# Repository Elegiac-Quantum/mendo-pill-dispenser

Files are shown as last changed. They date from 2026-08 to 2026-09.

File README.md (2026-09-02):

# Mendo 萌豆药盒

### ESP32-S3 smart pill dispenser and medication reminder by EQ Studio

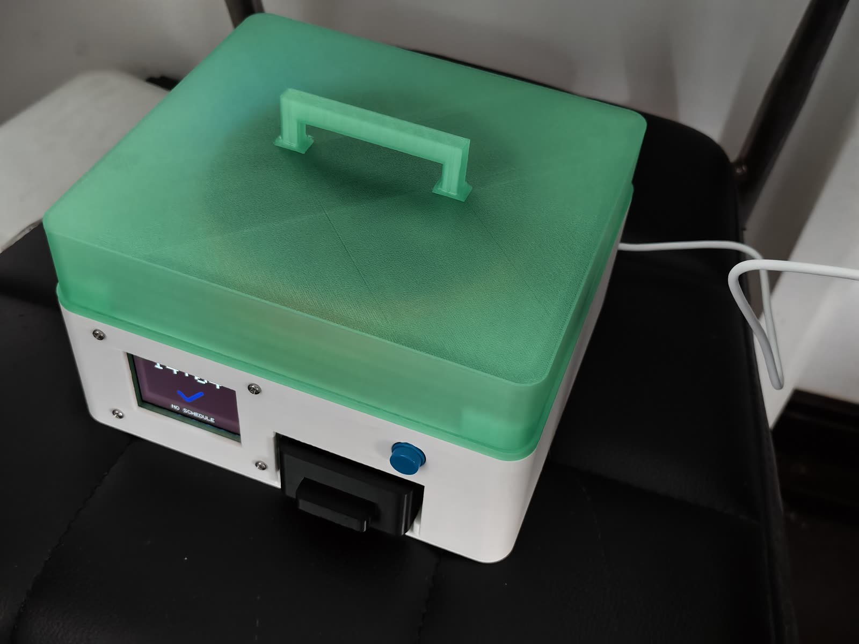
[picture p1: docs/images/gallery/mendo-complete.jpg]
Completed Mendo prototype


Mendo is an experimental ESP32-S3 smart pill dispenser and medication reminder
with a 3D-printed, 15-compartment rotary tray. It combines RTC scheduling,
caregiver web controls, audio alerts and MT6701 position feedback in a compact
assistive-technology prototype by EQ Studio.

This repository contains the ESP-IDF firmware, printable STL/3MF models,
editable OpenSCAD files, assembly documentation and photographs of working
physical prototypes.

**Experimental prototype, not a certified medical device. Do not use it as the
sole safeguard for a person's medication.** See [safety and review](docs/REVIEW.md).

## Hardware

- ALIENTEK DNESP32S3 development board, ESP32-S3 N16R8.
- 2.4-inch display, onboard audio, TF card and DS3231 clock module.
- Continuous-rotation MG996R, PCA9685 channel 0 and MT6701 tray-angle feedback.
- Fifteen preloaded compartments, 24 degrees per step, removable receiving cup.
- Physical confirmation button and local browser settings.

The caregiver loads doses in order. This is not a machine that identifies pills,
counts arbitrary pills, verifies ingestion or decides a medication plan.

## Prototype gallery

<table>
  <tr>
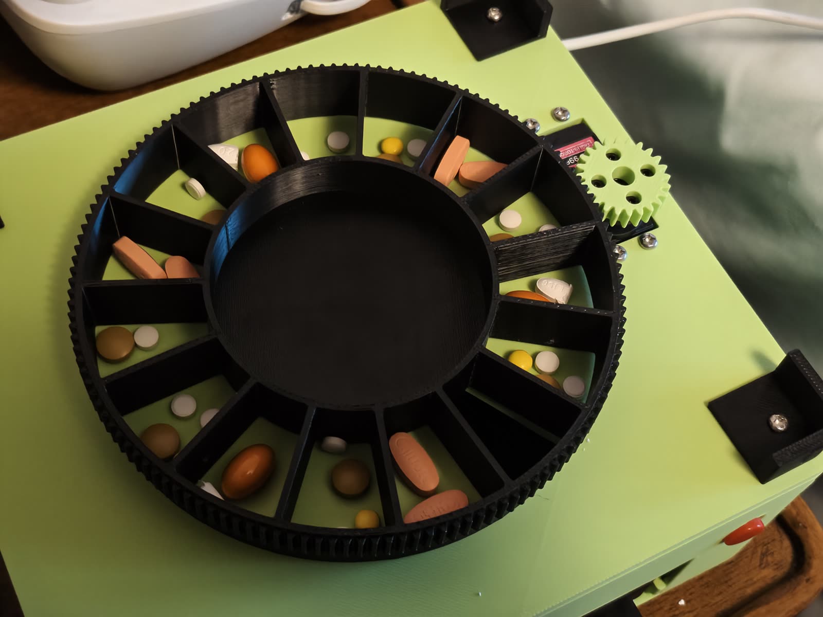
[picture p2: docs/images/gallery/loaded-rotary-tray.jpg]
Fifteen-compartment tray loaded for a mechanism test
    <td width="50%"><br><sub>Fifteen compartments loaded in sequence for a mechanism test.</sub></td>
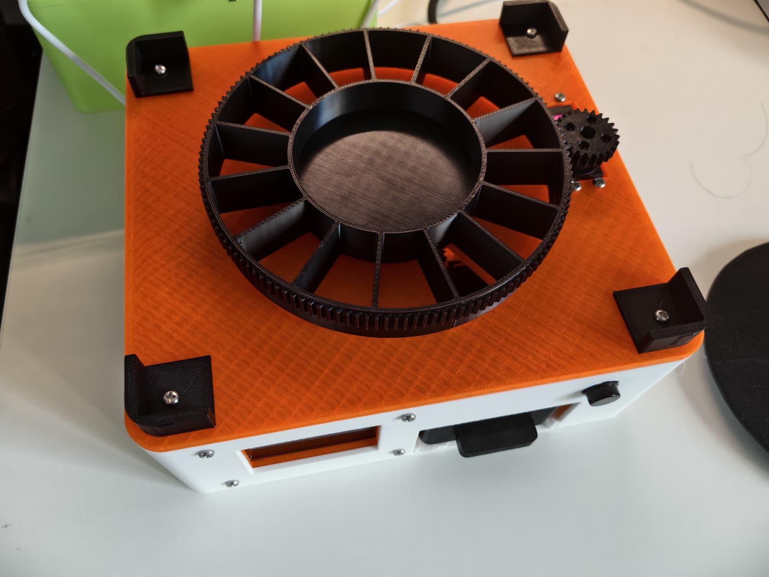
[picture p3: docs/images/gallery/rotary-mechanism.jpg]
Rotary tray and servo pinion
    <td width="50%"><br><sub>The tray's perimeter gear is driven by the servo pinion.</sub></td>
  </tr>
  <tr>
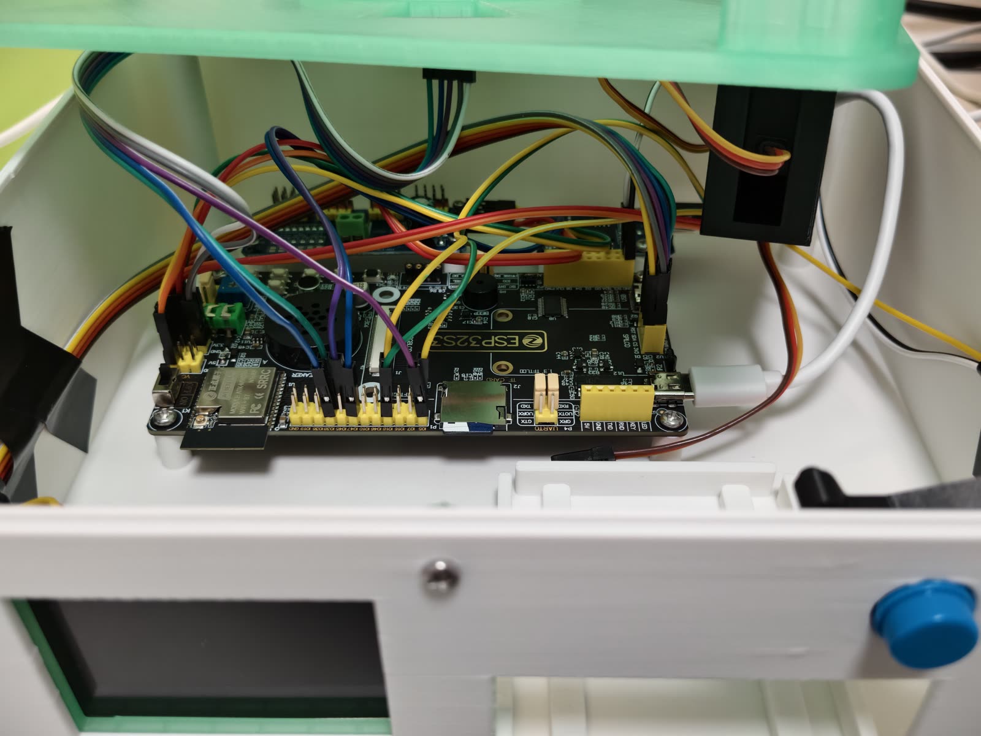
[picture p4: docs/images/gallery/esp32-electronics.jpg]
ESP32-S3 electronics inside the enclosure
    <td><br><sub>ESP32-S3 development board and prototype wiring inside the enclosure.</sub></td>
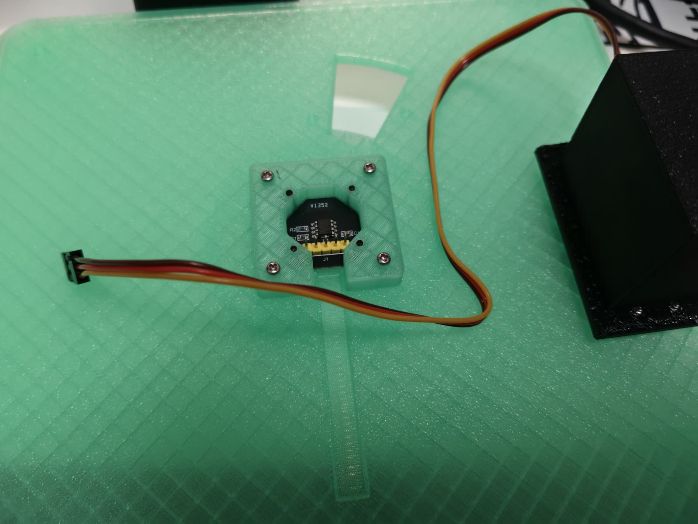
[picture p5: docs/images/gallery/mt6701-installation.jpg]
MT6701 angle sensor installation
    <td><br><sub>MT6701 angle-feedback module held by its printed adapter.</sub></td>
  </tr>
</table>

### From parts to prototype

<table>
  <tr>
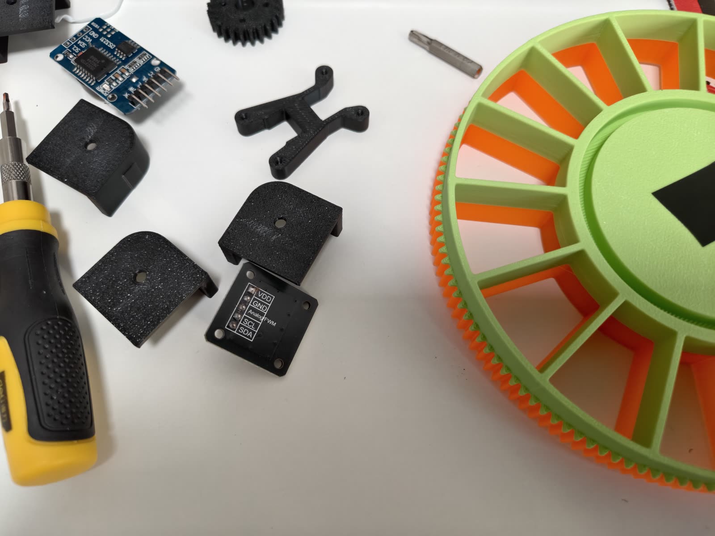
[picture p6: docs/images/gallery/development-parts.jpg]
Printed parts and sensor during development
    <td width="50%"><br><sub>Printed parts, sensor mounts and tray iterations during development.</sub></td>
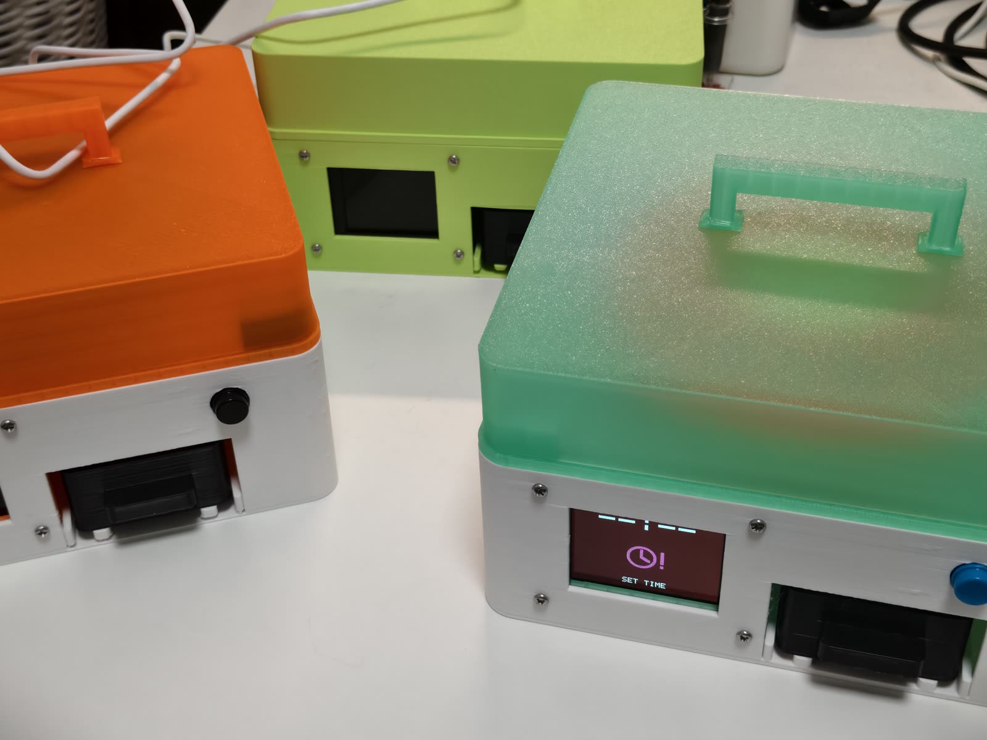
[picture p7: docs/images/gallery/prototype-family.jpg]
Three Mendo prototype builds
    <td width="50%"><br><sub>Several physical builds used to test fit, assembly and repeatability.</sub></td>
  </tr>
</table>

### Geometry previews

These OpenSCAD previews are rendered directly from every triangle in the
published STL geometry. They are not photographs and do not add parts that are
absent from the downloadable files.

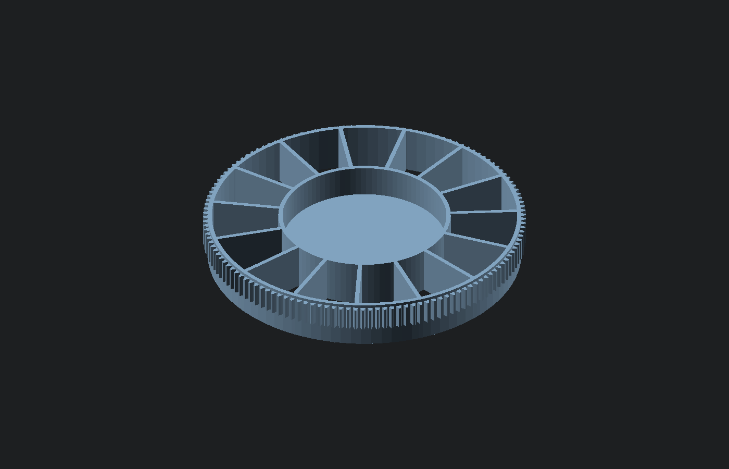
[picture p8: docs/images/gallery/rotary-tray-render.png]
OpenSCAD render of the 15-compartment tray


<table>
  <tr>
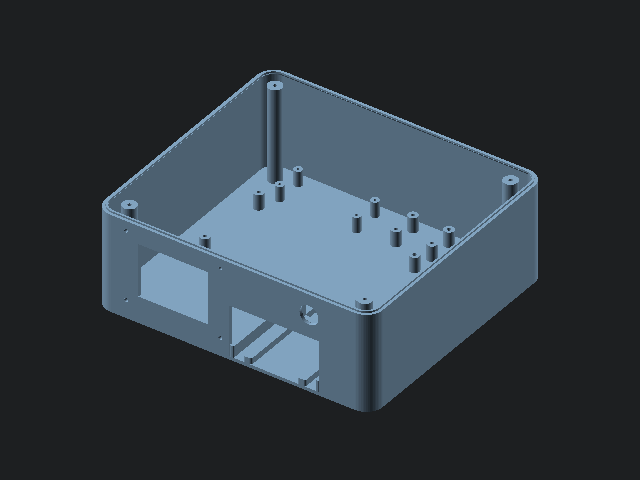
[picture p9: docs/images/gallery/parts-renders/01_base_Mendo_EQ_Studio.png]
Rendered branded base
    <td width="25%"><br><sub>Branded base</sub></td>
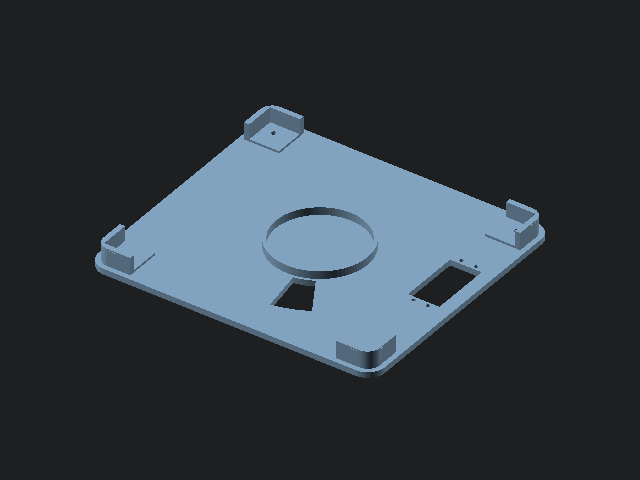
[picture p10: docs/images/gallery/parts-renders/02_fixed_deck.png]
Rendered fixed deck
    <td width="25%"><br><sub>Fixed deck</sub></td>
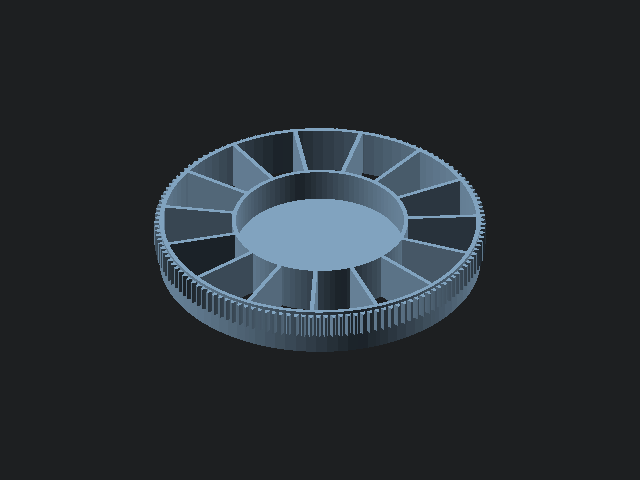
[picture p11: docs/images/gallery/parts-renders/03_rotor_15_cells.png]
Rendered rotary tray
    <td width="25%"><br><sub>Rotary tray</sub></td>
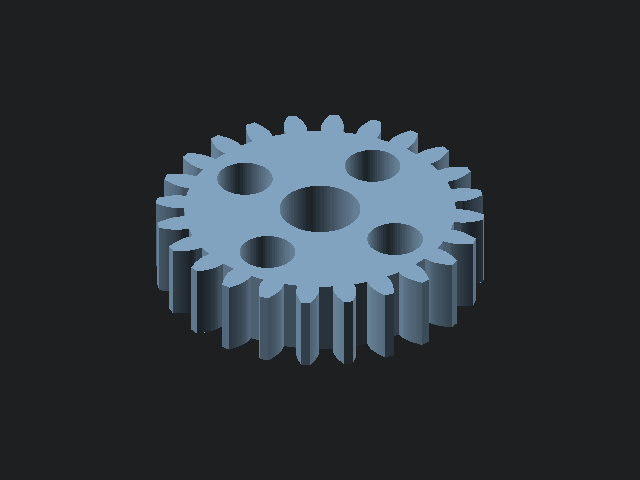
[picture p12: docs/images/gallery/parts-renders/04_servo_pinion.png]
Rendered servo pinion
    <td width="25%"><br><sub>Servo pinion</sub></td>
  </tr>
  <tr>
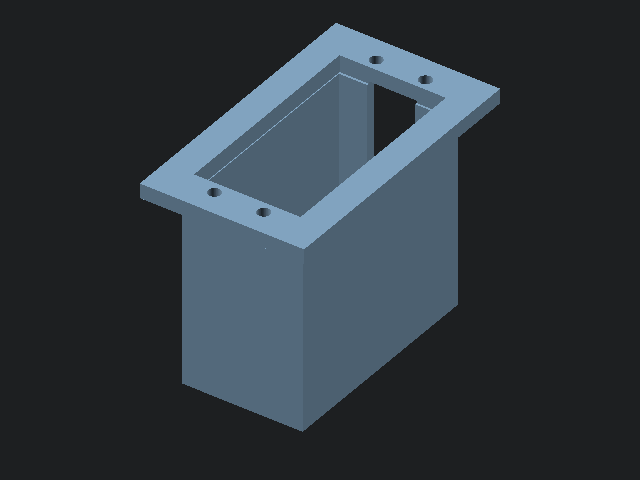
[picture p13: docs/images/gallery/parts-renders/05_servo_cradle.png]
Rendered servo cradle
    <td><br><sub>Servo cradle</sub></td>
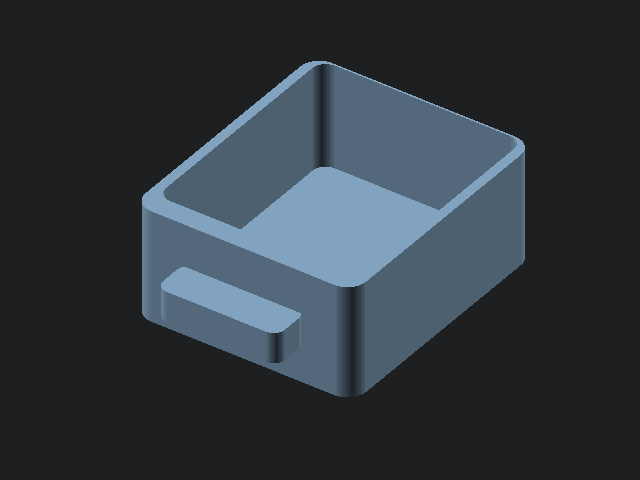
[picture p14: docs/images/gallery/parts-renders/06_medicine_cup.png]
Rendered medicine cup
    <td><br><sub>Medicine cup</sub></td>
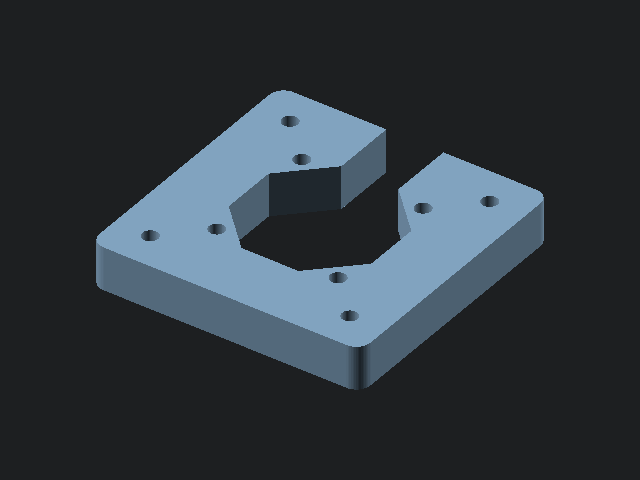
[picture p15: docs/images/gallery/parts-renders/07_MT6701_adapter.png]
Rendered MT6701 adapter
    <td><br><sub>MT6701 adapter</sub></td>
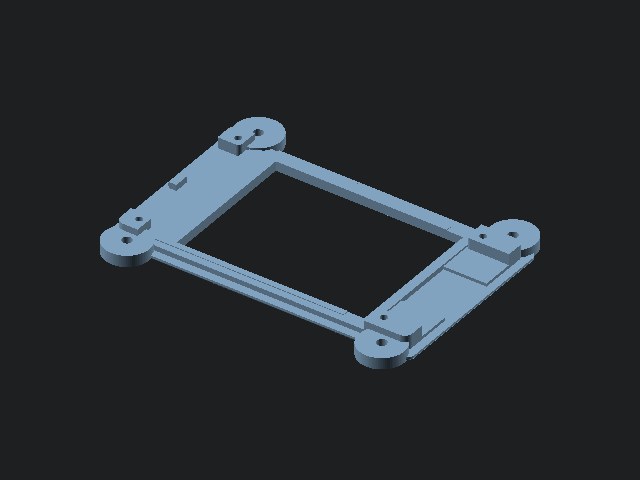
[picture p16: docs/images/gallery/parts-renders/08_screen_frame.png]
Rendered screen frame
    <td><br><sub>Screen frame</sub></td>
  </tr>
  <tr>
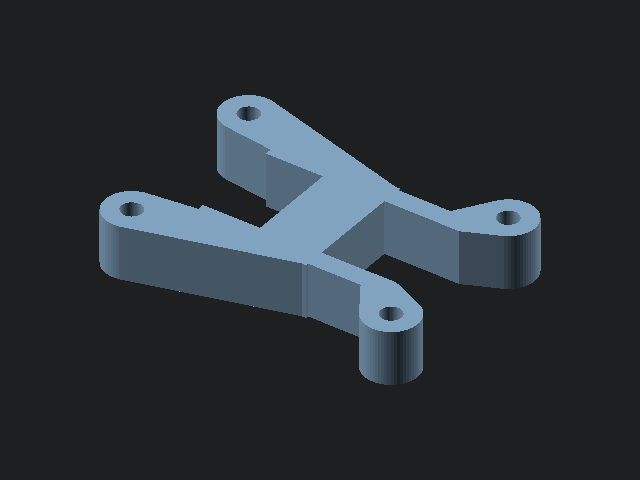
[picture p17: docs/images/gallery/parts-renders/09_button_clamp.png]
Rendered button clamp
    <td><br><sub>Button clamp</sub></td>
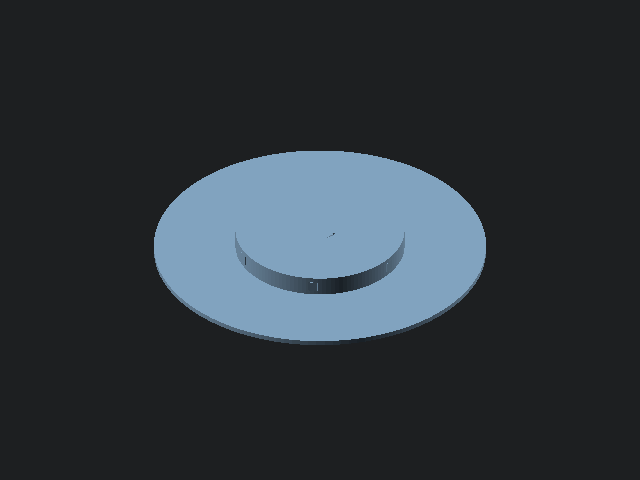
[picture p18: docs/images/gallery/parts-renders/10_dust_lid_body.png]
Rendered dust lid
    <td><br><sub>Dust lid</sub></td>
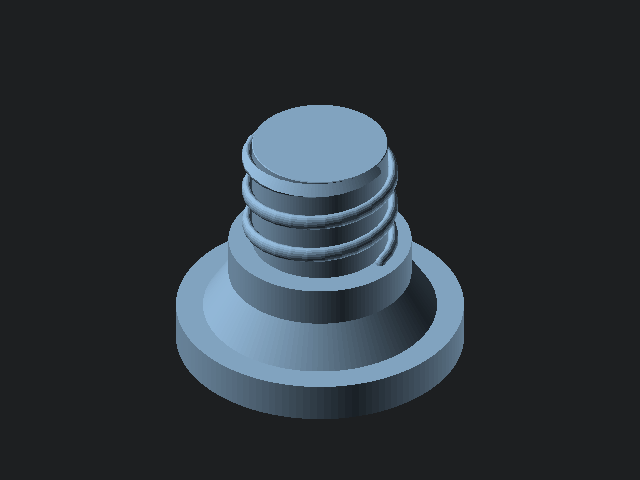
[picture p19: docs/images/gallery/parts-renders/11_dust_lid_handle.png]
Rendered lid handle
    <td><br><sub>Lid handle</sub></td>
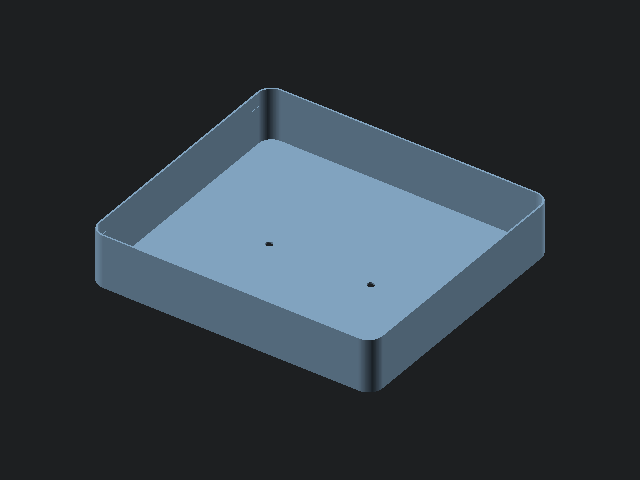
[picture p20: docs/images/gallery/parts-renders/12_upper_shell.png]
Rendered upper shell
    <td><br><sub>Upper shell</sub></td>
  </tr>
  <tr>
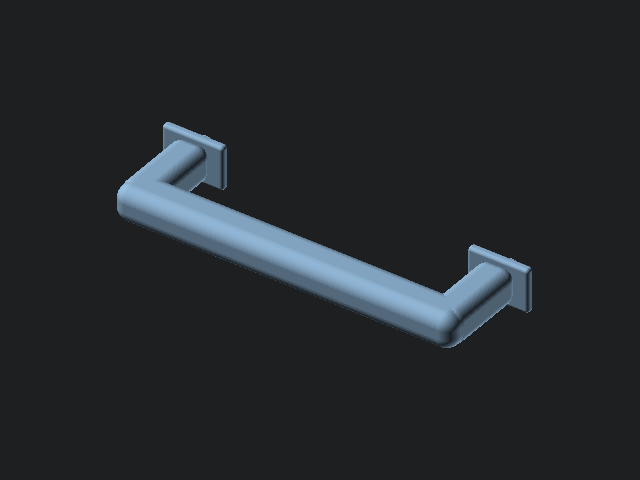
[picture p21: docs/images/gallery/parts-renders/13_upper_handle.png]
Rendered upper handle
    <td><br><sub>Upper handle</sub></td>
  </tr>
</table>

## Repository

| Folder | Contents |
| --- | --- |
| `firmware/` | ESP-IDF source candidate and host tests |
| `models/stl/` | Current selected printable parts; see the model notes |
| `models/cad/` | Editable CAD and underside EQ Studio attribution |
| `docs/` | Review, limitations and provenance |

Read [model notes](docs/MODELS.md) before printing. The original development
workspace, account settings, patient logs and private voice recordings are not included.

## Build

Use ESP-IDF **5.5.4**, target `esp32s3`, with its Python environment activated:

```sh
cd firmware
idf.py set-target esp32s3
idf.py build
```

Review the board pin mapping in `components/board_support/include` before wiring
or flashing. Public source includes neutral generated tones instead of private
voice recordings. It is not a byte-for-byte copy of firmware already installed.
AI wake is disabled in this stability-focused snapshot; do not expect voice wake
to work merely because the Xiaozhi integration source is present.

## Authorship and credit

Project author: **EQ Studio**, maintained on GitHub by **Elegiac-Quantum**.
Preferred credit: **Mendo by EQ Studio**, linked to this repository. Retain the
author notices and identify your modifications; do not present an unchanged copy
as your own original project or imply endorsement.

This is a public source-visible project, not currently an OSI open-source license
grant. Original material is reserved under [LICENSE](LICENSE.md). Third-party
components retain their own licenses. See [credits](THIRD_PARTY_NOTICES.md).

Publication history and file hashes help document this version's provenance;
they are not proof that every underlying idea was invented here, or a guarantee
against copying.

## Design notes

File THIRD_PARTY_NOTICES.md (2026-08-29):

# Sources and third-party credits

Mendo's project authorship is attributed to EQ Studio. This does not mean every
dependency, component, algorithm or earlier mechanism was created by EQ Studio.

- [Espressif ESP-IDF](https://github.com/espressif/esp-idf), version 5.5.4:
  installed separately; retain its Apache-2.0 and component-specific notices.
- ESP-SR, ESP Codec Dev, ESP WebSocket Client, ESP-DSP and Opus dependencies:
  resolved by the dependency manifests and lockfile. Their upstream notices and
  licenses remain applicable; SDK and managed-component caches are not bundled.
- [Xiaozhi ESP32](https://github.com/78/xiaozhi-esp32): implementation reference
  and service ecosystem. Xiaozhi service accounts and voice rights are separate.
- [Shaztech/Pilldispenser](https://github.com/Shaztech/Pilldispenser): an early
  mechanism and software reference. Original downloaded sample files are not
  included. Do not claim Mendo invented pill dispensers or their general concept.
- ALIENTEK DNESP32S3 vendor documentation and examples informed board mapping.
  Vendor PDFs, example archives and branding are not redistributed.
- [OpenSCAD MCAD](https://github.com/openscad/MCAD), used by gear CAD; install
  separately with OpenSCAD and retain its own notices for the library.

Generated neutral tones in this candidate are mathematical sine signals, not
family voice clones or licensed songs. The selected photograph is supplied by
the project owner and re-encoded without camera metadata.

A complete line-by-line third-party provenance review is still pending. This
notice is an inventory of known sources, not a claim that attribution alone
replaces permission. Unclear assets should stay out of a public release until
their provenance and terms are resolved.

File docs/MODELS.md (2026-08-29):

# Model selection

This candidate uses the later V16 base and V7 deck, rather than the stale
13-file package prepared before the final mounting revisions.

1. Base, with a 0.5 mm deep underside `Mendo by EQ Studio` engraving.
2. Fixed deck with integrated upper-shell feet and underside locating groove.
3. 15-compartment rotor gear.
4. 24-tooth pinion for the supplied servo horn.
5. MG996R cradle.
6. Direct-drop receiving cup.
7. 6 mm MT6701 adapter, 17 mm sensor and 28 mm deck hole spacing.
8. Screen frame with its inner window aligned to the base.
9. Four-hole 6 mm button back clamp.
10. Threaded dust-lid body.
11. Threaded dust-lid handle.
12. Upper shell.
13. Rounded upper-shell handle.

The deck has integrated feet: do not add the old loose four-foot set. Old board
edge clamp arrays and the one-piece dust lid are not this version's assembly.

STLs are source meshes, not printer profiles. Check orientation, material,
clearances and supports in your slicer. A combined 3MF is an object collection,
not a promise that all parts fit on one print plate. Engraving has not been
physically printed in this review. Preserve the original unbranded base as a
reference; only print one base.

OpenSCAD CAD uses the MCAD library shipped with OpenSCAD. Some older modules in
the source describe earlier assemblies; the STL list above defines this
candidate. The inherited name `as5600` in a CAD path is historical; this
prototype's sensor is MT6701.

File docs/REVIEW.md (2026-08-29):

# Release-candidate review

Status: local review candidate, not a safety certification or clinical validation.

## Verified during this review

- Existing host C test suite: 14/14 pass after the final motion-safety change.
- Added volume regression executed real production getter/setter with an NVS
  test backend enforcing the 15-character key limit. Before the fix, lowering
  volume to 35 reverted to 100 on simulated reboot. After the fix, 35 and mute
  persist. The setter also records completion of the volume migration.
- Development ESP-IDF firmware rebuilt successfully after this change.
- Added an alignment contract regression. Overshoot outside the same 1.5-degree
  settling tolerance is now reported as `overshot_target`, rather than success.
- Thirteen selected STL files passed closed, positive-volume mesh checks. The
  generated 3MF was reopened and contains 13 separate objects with triangles.
- No physical dispensing or firmware flashing was performed in this review.

## Findings that limit use

1. **Uncollected doses can accumulate.** The next scheduled occurrence proceeds
   even when the prior reminder was not acknowledged. There is no cup-contents
   detector. Never interpret button acknowledgement as verified ingestion.
2. **The overshoot software fault is corrected but needs physical retesting.**
   The controller now fails closed outside 1.5 degrees and never reverses. This
   can turn a formerly reported success into a visible dispense fault, which is
   intentional. The changed build was not flashed or physically exercised here.
3. **Duplicate suppression has limited history.** NVS `dose_state/latest` stores
   only one occurrence; reminder `last_N` keys use list indices. Clock rollback,
   reordering/deleting schedules or interrupted multi-schedule processing need
   persistent per-occurrence coverage. Current tests do not prove those cases.
4. **Scheduling and playback share a task.** Removing the endless alarm loop
   prevents that known lockup, but synchronous playback can still delay a later
   schedule. The exact-minute matcher needs a catch-up policy before long uploads
   or many simultaneous schedules can be considered reliable.
5. **Local security is limited.** Caregiver PIN is optional, local HTTP is not
   encrypted, and the default hotspot password is derived from the MAC address.
   Use a unique hotspot password and PIN on a trusted network; do not forward
   the device's HTTP port to the Internet. Remote control needs a separately
   secured HTTPS service; no live service credentials are published here.
6. **Audio still requires in-room testing.** The 12x software gain saturates
   peaks. A successful build cannot establish audibility, intelligibility,
   absence of distortion or suitability for a particular person's hearing.
7. **AI is not a verified feature of this candidate.** The stability snapshot
   disables the wake task after prior failures. The online service is separate.

These findings must not be replaced with a blanket statement that all functions
are working. Use placebo contents for engineering tests. A caregiver must review
the tray, cup, time, loading order and power-recovery state.

## Excluded from public files

SDK caches, binaries/flashed images, NVS data, device account bindings, Wi-Fi
settings, fleet credentials, logs, patient schedules, family recordings, APK
signing material, vendor PDFs, presentation files and obsolete prototype trees.

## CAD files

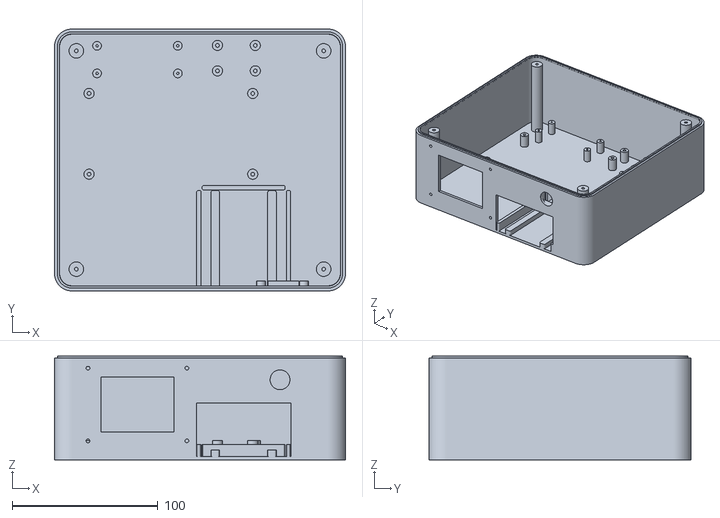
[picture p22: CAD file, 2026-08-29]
models/cad/base_unbranded.stl
200.0 x 180.0 x 71.2

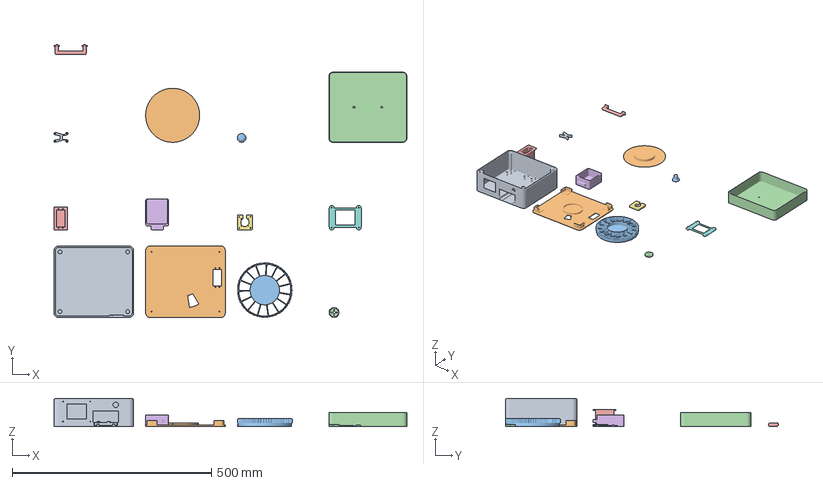
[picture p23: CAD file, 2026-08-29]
models/Mendo_ALL_PARTS_CANDIDATE.3mf
886.0 x 685.8 x 71.2 mm
01_base_Mendo_EQ_Studio
02_fixed_deck
03_rotor_15_cells
04_servo_pinion
05_servo_cradle
06_medicine_cup
07_MT6701_adapter
08_screen_frame
09_button_clamp
10_dust_lid_body
11_dust_lid_handle
12_upper_shell
13_upper_handle

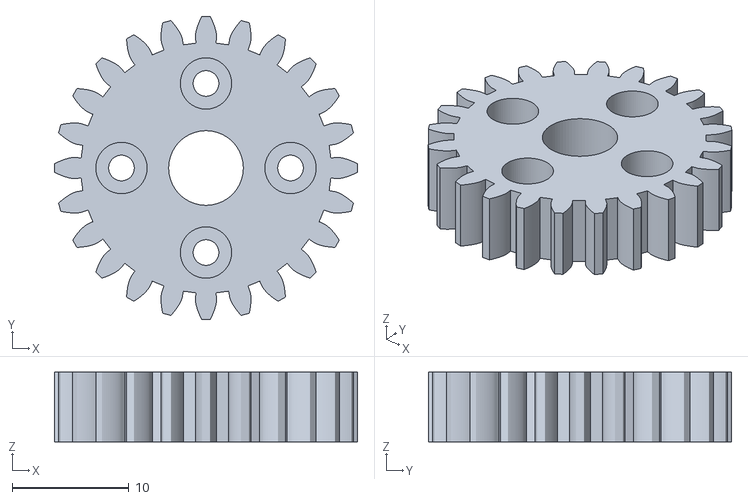
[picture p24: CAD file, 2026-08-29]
models/stl/04_servo_pinion.stl
26.0 x 26.0 x 6.00

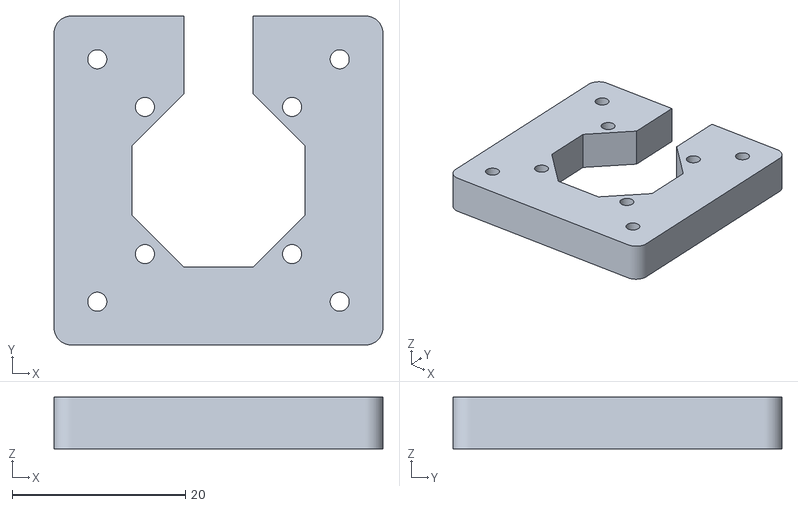
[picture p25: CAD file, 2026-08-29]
models/stl/07_MT6701_adapter.stl
38.0 x 38.0 x 6.00

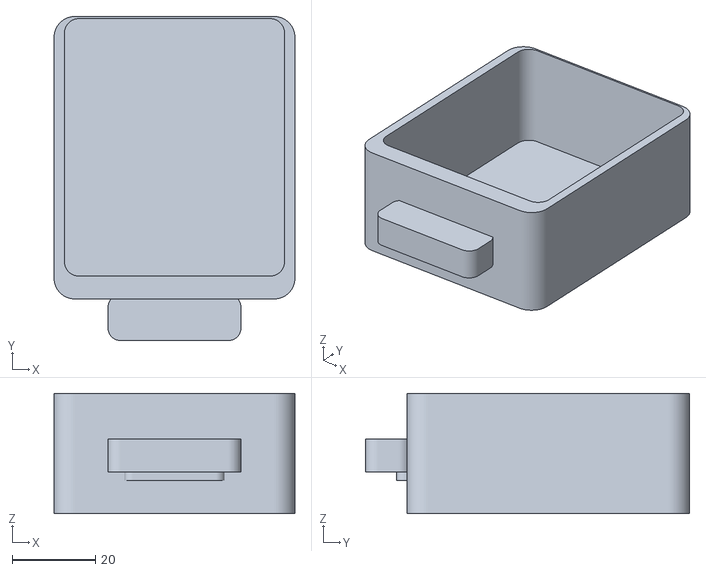
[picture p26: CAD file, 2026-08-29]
models/stl/06_medicine_cup.stl
58.0 x 78.0 x 29.0

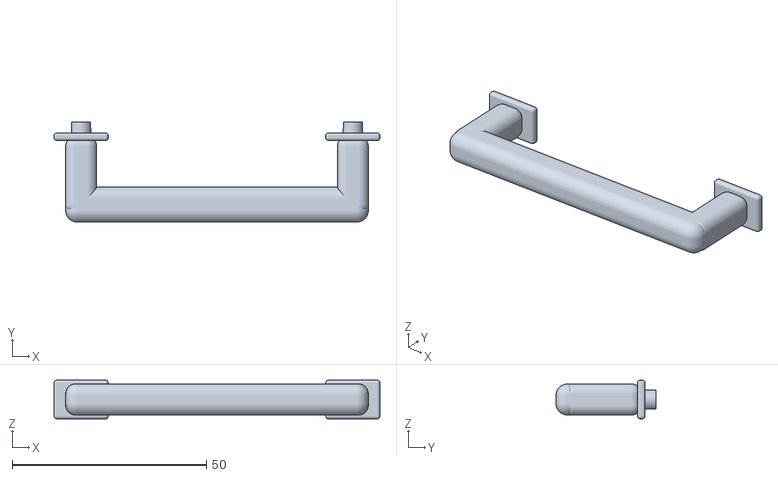
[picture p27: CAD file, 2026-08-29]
models/stl/13_upper_handle.stl
84.0 x 25.8 x 10.00

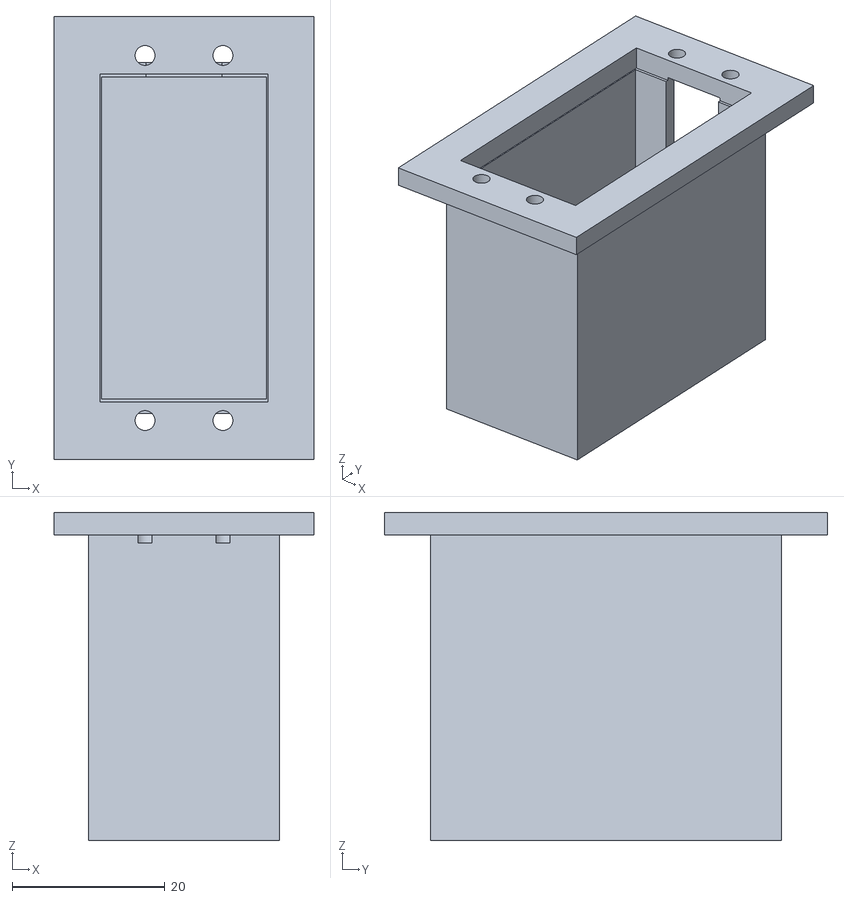
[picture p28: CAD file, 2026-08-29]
models/stl/05_servo_cradle.stl
34.0 x 58.0 x 43.0

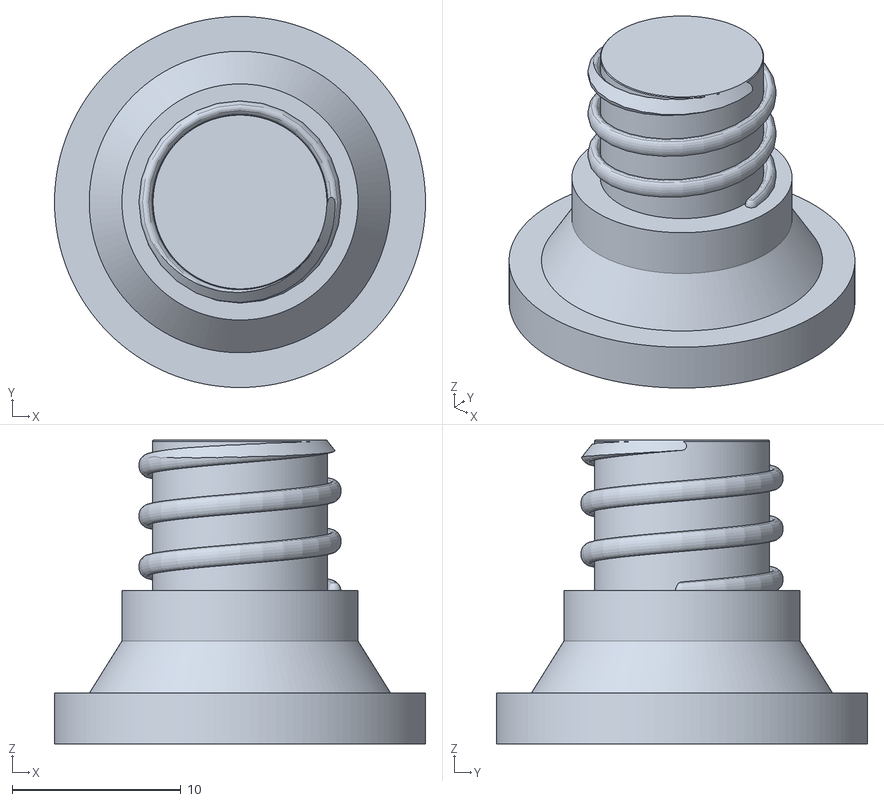
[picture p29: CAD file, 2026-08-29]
models/stl/11_dust_lid_handle.stl
22.0 x 22.0 x 18.0

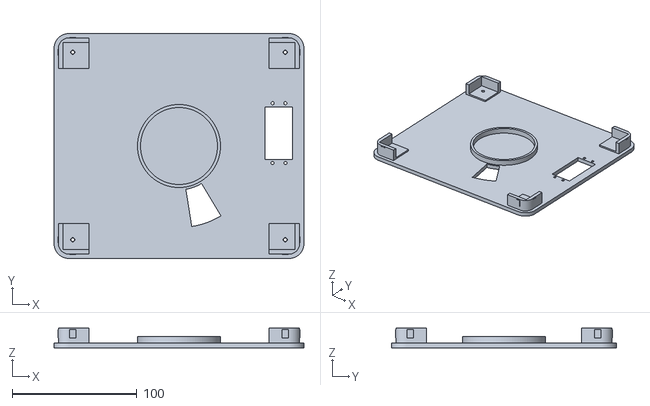
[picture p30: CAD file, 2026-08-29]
models/stl/02_fixed_deck.stl
200.0 x 180.0 x 16.0

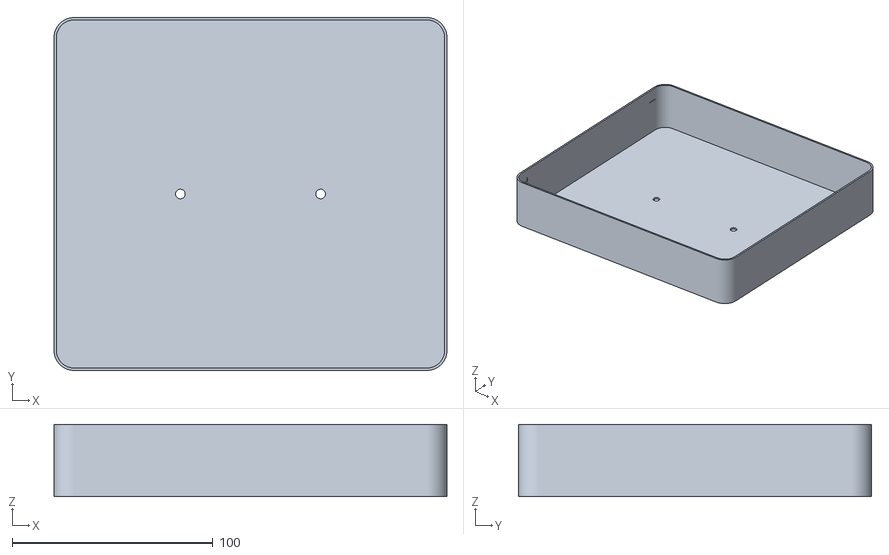
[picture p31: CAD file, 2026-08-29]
models/stl/12_upper_shell.stl
196.0 x 176.0 x 36.0

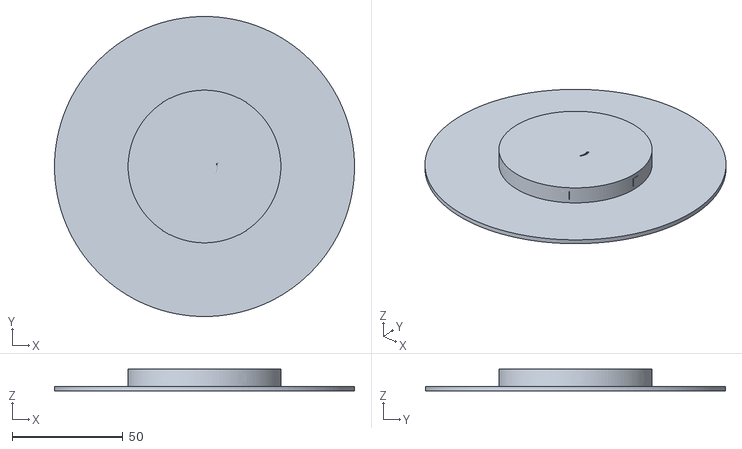
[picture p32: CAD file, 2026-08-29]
models/stl/10_dust_lid_body.stl
135.6 x 135.6 x 9.80

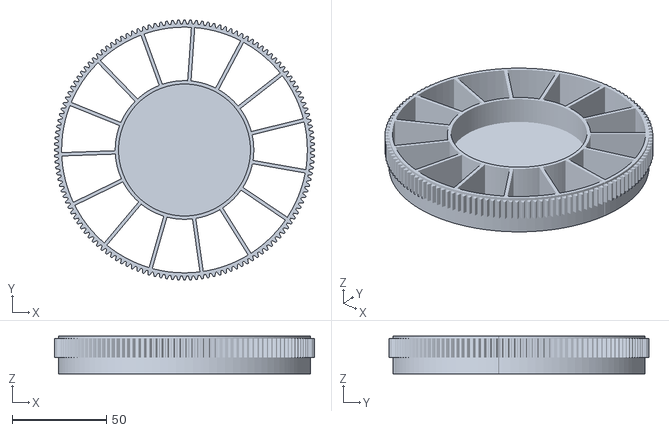
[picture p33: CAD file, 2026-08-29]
models/stl/03_rotor_15_cells.stl
138.0 x 138.0 x 20.0

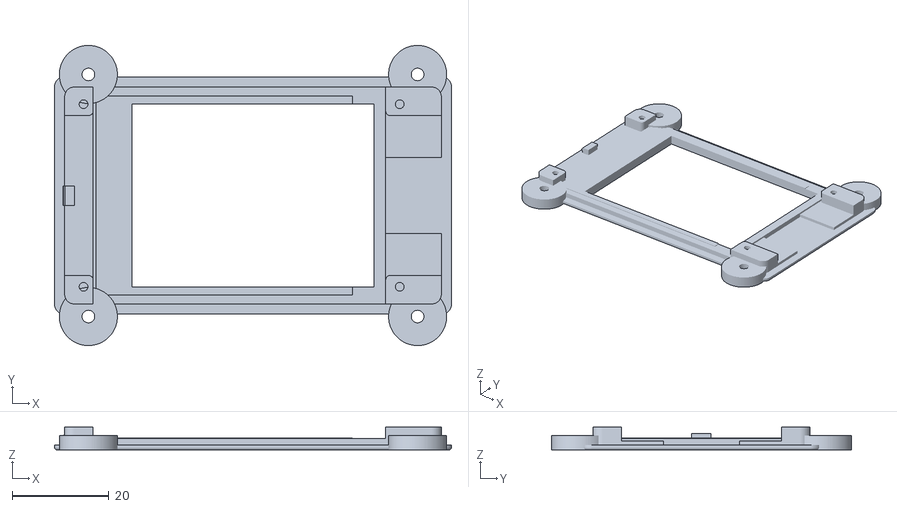
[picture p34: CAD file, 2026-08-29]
models/stl/08_screen_frame.stl
82.0 x 62.0 x 4.70

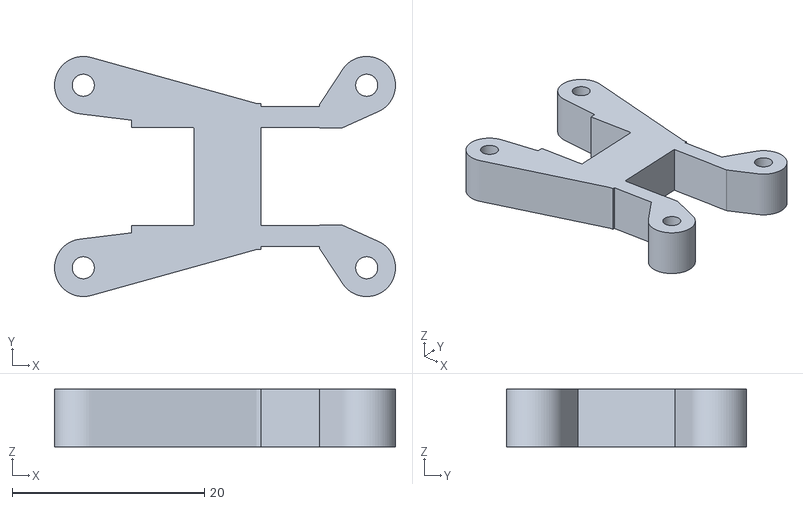
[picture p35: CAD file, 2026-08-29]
models/stl/09_button_clamp.stl
35.5 x 25.0 x 6.00

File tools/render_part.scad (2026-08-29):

// Headless OpenSCAD wrapper used to generate accurate README previews.
// Pass part_path and part_color with -D on the command line.

$fn = 64;
color(part_color)
    import(part_path, convexity = 12);

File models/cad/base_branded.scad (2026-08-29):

// Mendo by EQ Studio. Underside engraving only; all fit geometry is preserved.
// Source: V16 base(), 200 x 180 x 71.2 mm including locating lip.
// The 0.5 mm recess leaves 1.9 mm of the original 2.4 mm floor.
use <mg996r_as5600_gear_v1/mg996r_as5600_gear_v1.scad>
difference() {
    base();
    translate([0,20,0.5]) rotate([180,0,0])
        linear_extrude(height=0.6)
            text("Mendo by EQ Studio", size=5,
                 font="Liberation Sans:style=Bold", halign="center", valign="center");
}

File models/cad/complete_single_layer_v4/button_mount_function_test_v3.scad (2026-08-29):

// Functional button mounting coupon: wall section + screw-on U clamp.
// Measured PCB: 20 x 13 mm; button centre 7 mm from left edge.
$fn = 64;
part = is_undef(part) ? "print_plate" : part;

wall_t = 2.4;
coupon = [40,30];
button_d = 13.6;
board = [20.0,13.0,1.6];
fit = 0.35;
board_cx = board[0]/2-7.0; // +3 mm relative to button centre
guide_t = 1.2;
switch_body = [11.5,11.5,3.0];
moving_neck_h = 4.5;
cap_d = 13.0;
cap_h = 5.0;
seat_h = switch_body[2]+board[2]-0.1; // 4.5 mm; 0.1 mm clamp preload
m2_pilot = 1.7;
m2_clear = 2.3;
screw_x_left = -13.0;
screw_x_right = 16.5;
screw_xs = [screw_x_left,screw_x_right];
screw_y = 9.5;
boss_d = 6.0;
clamp_t = 6.0;

left = board_cx-(board[0]+fit)/2;
right = board_cx+(board[0]+fit)/2;
bottom = -(board[1]+fit)/2;
top = (board[1]+fit)/2;

module wall_coupon() {
    difference() {
        union() {
            difference() {
                translate([0,0,wall_t/2]) cube([coupon[0],coupon[1],wall_t],center=true);
                translate([0,0,-0.1]) cylinder(d=button_d,h=wall_t+0.2);
            }
            // Three locating edges; the right side is open for the 3-pin plug.
            translate([left-guide_t/2,0,wall_t+seat_h/2])
                cube([guide_t,board[1]+fit+2*guide_t,seat_h],center=true);
            for(y=[bottom-guide_t/2,top+guide_t/2])
                translate([(left+right)/2,y,wall_t+seat_h/2])
                    cube([right-left,guide_t,seat_h],center=true);
            for(x=screw_xs,y=[-screw_y,screw_y])
                translate([x,y,wall_t]) cylinder(d=boss_d,h=seat_h);
        }
        for(x=screw_xs,y=[-screw_y,screw_y])
            // Blind thread paths; use M2 x 10 mm with the 6 mm clamp.
            translate([x,y,0.8]) cylinder(d=m2_pilot,h=wall_t+seat_h-0.6);
    }
}

module back_clamp() {
    bridge_x = board_cx; // user-validated clear centre band, away from solder joints
    bridge_w = 7.0;      // includes 2 mm extra support toward the M2 holes
    bridge_cx = bridge_x-1.0; // keep the far edge fixed; extend only hole-ward
    difference() {
        union() {
            // Centre bridge avoids the solder joints near the former left edge.
            translate([bridge_cx,0,clamp_t/2])
                cube([bridge_w,board[1]+2.2,clamp_t],center=true);
            for(y=[-6.2,6.2])
                translate([(left+right)/2-0.4,y,clamp_t/2])
                    cube([right-left+0.8,2.2,clamp_t],center=true);
            // Existing left pair connects to the strengthened centre bridge.
            for(y=[-screw_y,screw_y])
                hull() {
                    translate([screw_x_left,y,0]) cylinder(d=boss_d,h=clamp_t);
                    translate([bridge_cx,y*0.66,clamp_t/2])
                        cube([bridge_w,2.4,clamp_t],center=true);
                }
            // New right pair joins the top/bottom rails while leaving the
            // central 3-pin connector path completely open.
            for(y=[-screw_y,screw_y])
                hull() {
                    translate([screw_x_right,y,0]) cylinder(d=boss_d,h=clamp_t);
                    translate([right-0.4,y*0.66,clamp_t/2])
                        cube([2.4,2.4,clamp_t],center=true);
                }
        }
        for(x=screw_xs,y=[-screw_y,screw_y])
            translate([x,y,-0.1]) cylinder(d=m2_clear,h=clamp_t+0.2);
    }
}

module print_plate() {
    translate([-23,0,0]) wall_coupon();
    translate([22,0,0]) back_clamp();
}

module assembly_preview() {
    wall_coupon();
    // Conservative reference for the measured button stack.
    color("Orange",0.8)
        translate([0,0,wall_t+switch_body[2]/2])
            cube(switch_body,center=true);
    color("Orange",0.8)
        translate([0,0,wall_t-moving_neck_h/2])
            cylinder(d=9.0,h=moving_neck_h,center=true);
    color("Red",0.8)
        translate([0,0,wall_t-moving_neck_h-cap_h/2])
            cylinder(d=cap_d,h=cap_h,center=true);
    color("FireBrick",0.7)
        translate([board_cx,0,wall_t+switch_body[2]+board[2]/2])
            cube(board,center=true);
    color("DimGray") translate([0,0,wall_t+seat_h]) back_clamp();
}

if(part == "wall") wall_coupon();
else if(part == "clamp") back_clamp();
else if(part == "assembly") assembly_preview();
else print_plate();

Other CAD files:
models/stl/01_base_Mendo_EQ_Studio.stl
models/cad/complete_single_layer_v4/complete_single_layer_v4.scad
models/cad/complete_single_layer_v4/mt6701_deck_adapter_17mm.scad
models/cad/complete_single_layer_v4/rotor_dust_lid_15cell.scad
models/cad/complete_single_layer_v4/upper_shell_handle_v2.scad
models/cad/complete_single_layer_v4/upper_shell_snap_v2.scad
models/cad/mg996r_as5600_gear_v1/mg996r_as5600_gear_v1.scad
models/cad/two_part_carousel_v3/two_part_carousel_v3.scad

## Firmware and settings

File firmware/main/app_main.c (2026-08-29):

#include <inttypes.h>

#include "esp_chip_info.h"
#include "esp_event.h"
#include "esp_flash.h"
#include "esp_heap_caps.h"
#include "esp_log.h"
#include "esp_netif.h"
#include "esp_system.h"
#include "driver/uart.h"
#include "esp_adc/adc_oneshot.h"
#include "freertos/FreeRTOS.h"
#include "freertos/task.h"
#include "nvs_flash.h"

#include "board_support/board.h"
#include "pill_ai_transport/transport.h"
#include "pill_app/app.h"
#include "pill_web/web.h"

static const char *TAG = "smartpill";

static void diagnose_mt6701_output(void)
{
    adc_oneshot_unit_handle_t adc = NULL;
    const adc_oneshot_unit_init_cfg_t unit_config = {
        .unit_id = ADC_UNIT_1,
    };
    esp_err_t error = adc_oneshot_new_unit(&unit_config, &adc);
    if (error != ESP_OK) {
        ESP_LOGW(TAG, "MT_OUTPUT error=%s", esp_err_to_name(error));
        return;
    }
    const adc_oneshot_chan_cfg_t channel_config = {
        .atten = ADC_ATTEN_DB_12,
        .bitwidth = ADC_BITWIDTH_12,
    };
    error = adc_oneshot_config_channel(adc, ADC_CHANNEL_4, &channel_config);
    int minimum = 4095, maximum = 0;
    int64_t total = 0;
    int valid = 0;
    if (error == ESP_OK) {
        for (int sample = 0; sample < 1000; ++sample) {
            int raw = 0;
            if (adc_oneshot_read(adc, ADC_CHANNEL_4, &raw) == ESP_OK) {
                if (raw < minimum) minimum = raw;
                if (raw > maximum) maximum = raw;
                total += raw;
                valid++;
            }
            esp_rom_delay_us(100);
        }
    }
    adc_oneshot_del_unit(adc);
    ESP_LOGW(TAG, "MT_OUTPUT gpio=5 samples=%d min=%d max=%d avg=%d span=%d error=%s",
             valid, valid ? minimum : -1, valid ? maximum : -1,
             valid ? (int)(total / valid) : -1,
             valid ? maximum - minimum : -1, esp_err_to_name(error));
}

static void calibration_console(void *unused)
{
    (void)unused;
    ESP_LOGW(TAG, "CAL console ready: send D for MT6701 diagnostics, A for analog output, S to scan safe P1 pins, or T for one empty-tray move");
    for (;;) {
        uint8_t command = 0;
        if (uart_read_bytes(UART_NUM_0, &command, 1, pdMS_TO_TICKS(200)) != 1) continue;
        if (command == 'D') {
            int sda = -1, scl = -1, address = -1;
            uint16_t raw = 0;
            float degrees = 0.0f;
            board_mt6701_diagnose(&sda, &scl, &address);
            esp_err_t mt_error = board_mt6701_read(&raw, &degrees);
            ESP_LOGW(TAG,
                     "MT_DIAG ok=%d sda=%d scl=%d address=%d raw=%u angle=%.2f error=%s",
                     mt_error == ESP_OK, sda, scl, address, raw, degrees,
                     esp_err_to_name(mt_error));
            int half_period_us = -1;
            bool timing_ok = board_mt6701_diagnose_timing(&half_period_us);
            ESP_LOGW(TAG, "MT_TIMING ok=%d half_us=%d approx_khz=%d",
                     timing_ok, half_period_us,
                     timing_ok ? 500 / half_period_us : 0);
            continue;
        }
        if (command == 'S') {
            int sda_gpio = -1, scl_gpio = -1;
            bool found = board_mt6701_scan_safe_p1(&sda_gpio, &scl_gpio);
            ESP_LOGW(TAG, "MT_SCAN found=%d sda_gpio=%d scl_gpio=%d",
                     found, sda_gpio, scl_gpio);
            vTaskDelay(pdMS_TO_TICKS(200));
            esp_restart();
        }
        if (command == 'A') {
            diagnose_mt6701_output();
            continue;
        }
        if (command == 'E') {
            int sda_gpio = -1, scl_gpio = -1;
            bool found = board_mt6701_scan_known_buses(&sda_gpio, &scl_gpio);
            ESP_LOGW(TAG, "MT_EXT_SCAN found=%d sda_gpio=%d scl_gpio=%d",
                     found, sda_gpio, scl_gpio);
            vTaskDelay(pdMS_TO_TICKS(200));
            esp_restart();
        }
        if (command != 'T') continue;
        bool success = board_servo_cycle_channel(0);
        float start = 0.0f, target = 0.0f, final = 0.0f, error = 0.0f;
        const char *reason = "unknown";
        board_servo_last_motion(&start, &target, &final, &error, &reason);
        ESP_LOGW(TAG,
                 "CAL_RESULT success=%d start=%.2f target=%.2f final=%.2f error=%.2f reason=%s",
                 success, start, target, final, error, reason);
    }
}

void app_main(void)
{
    esp_chip_info_t chip_info;
    uint32_t flash_size = 0;

    esp_chip_info(&chip_info);
    ESP_ERROR_CHECK(esp_flash_get_size(NULL, &flash_size));

    ESP_LOGI(TAG, "Smart Pill Dispenser Prototype 2 rotary");
    ESP_LOGI(TAG, "ESP32-S3 cores=%u revision=%u", chip_info.cores, chip_info.revision);
    ESP_LOGI(TAG, "Flash=%" PRIu32 " bytes PSRAM=%u bytes",
             flash_size,
             heap_caps_get_total_size(MALLOC_CAP_SPIRAM));

    esp_err_t error = nvs_flash_init();
    if (error == ESP_ERR_NVS_NO_FREE_PAGES || error == ESP_ERR_NVS_NEW_VERSION_FOUND) {
        ESP_ERROR_CHECK(nvs_flash_erase());
        error = nvs_flash_init();
    }
    ESP_ERROR_CHECK(error);
    ESP_ERROR_CHECK(esp_netif_init());
    ESP_ERROR_CHECK(esp_event_loop_create_default());

    board_health_t health;
    ESP_ERROR_CHECK(board_init(&health));

    esp_err_t console_error = uart_driver_install(UART_NUM_0, 256, 0, 0, NULL, 0);
    if (console_error != ESP_OK && console_error != ESP_ERR_INVALID_STATE) {
        ESP_LOGW(TAG, "COM8 calibration input unavailable: %s",
                 esp_err_to_name(console_error));
    }

    if (xTaskCreate(calibration_console, "cal_console", 3072, NULL, 3, NULL) !=
        pdPASS) {
        ESP_LOGW(TAG, "Calibration console unavailable");
    }

    error = pill_app_start();
    if (error != ESP_OK) {
        ESP_LOGE(TAG, "Safety controller failed: %s; movement remains locked",
                 esp_err_to_name(error));
    }

    error = pill_web_start();
    if (error != ESP_OK) {
        ESP_LOGW(TAG, "Caregiver web UI unavailable: %s", esp_err_to_name(error));
    }
    pill_ai_check_activation_async();
}

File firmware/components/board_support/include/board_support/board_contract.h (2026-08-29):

#ifndef BOARD_SUPPORT_BOARD_CONTRACT_H
#define BOARD_SUPPORT_BOARD_CONTRACT_H

#include <stdbool.h>
#include <stdint.h>

enum {
    BOARD_XL9555_PORT0_SAFE_OUTPUT = 1U << 3,
    BOARD_XL9555_PORT0_BOOT_OUTPUT = 0x08,
    BOARD_XL9555_PORT1_BOOT_OUTPUT = 0x0d,
    BOARD_XL9555_PORT0_BOOT_CONFIG = 0x03,
    BOARD_XL9555_PORT1_BOOT_CONFIG = 0xf0,
    BOARD_LCD_BGR_ORDER = 1,
    BOARD_TF_FORMAT_IF_MOUNT_FAILED = 0,
    BOARD_I2C_SDA_GPIO = 41,
    BOARD_I2C_SCL_GPIO = 42,
    BOARD_RTC_I2C_SDA_GPIO = 17,
    BOARD_RTC_I2C_SCL_GPIO = 18,
    BOARD_SPI_MOSI_GPIO = 11,
    BOARD_SPI_SCLK_GPIO = 12,
    BOARD_SPI_MISO_GPIO = 13,
    BOARD_LCD_CS_GPIO = 21,
    BOARD_LCD_DC_GPIO = 40,
    BOARD_TF_CS_GPIO = 2,
    BOARD_AUDIO_MCLK_GPIO = 3,
    BOARD_AUDIO_BCLK_GPIO = 46,
    BOARD_AUDIO_LRCLK_GPIO = 9,
    BOARD_AUDIO_DATA_OUT_GPIO = 10,
    BOARD_AUDIO_DATA_IN_GPIO = 14,
    BOARD_AUDIO_SAMPLE_RATE = 16000,
    BOARD_AUDIO_BITS = 16,
    BOARD_AUDIO_CHANNELS = 1,
    BOARD_AUDIO_FIRST_TEST_VOLUME = 35,
    BOARD_PCA9685_SDA_GPIO = 47,
    BOARD_PCA9685_SCL_GPIO = 48,
    BOARD_PCA9685_ADDRESS = 0x40,
    BOARD_PATIENT_BUTTON_GPIO = 4,
    BOARD_MT6701_SDA_GPIO = 39,
    BOARD_MT6701_SCL_GPIO = 38,
    BOARD_MT6701_ADDRESS = 0x06,
    BOARD_USB_D_MINUS_GPIO = 19,
    BOARD_USB_D_PLUS_GPIO = 20,
};

bool board_servo_config_valid(uint16_t minimum_us,
                              uint16_t maximum_us,
                              uint16_t closed_us,
                              uint16_t release_us);
uint16_t board_pca9685_pulse_count(uint16_t pulse_us);
bool board_audio_config_valid(uint32_t sample_rate,
                              uint8_t bits,
                              uint8_t channels,
                              uint8_t volume);
bool board_rotary_alignment_acceptable(float signed_error_degrees,
                                        float tolerance_degrees);

#endif

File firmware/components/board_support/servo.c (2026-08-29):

#include "board_support/board.h"

#include <math.h>
#include <string.h>

#include "board_support/board_contract.h"
#include "driver/gpio.h"
#include "esp_check.h"
#include "esp_log.h"
#include "esp_rom_sys.h"
#include "freertos/FreeRTOS.h"
#include "freertos/semphr.h"
#include "freertos/task.h"
#include "nvs.h"

enum {
    SERVO_MINIMUM_US = 500,
    SERVO_MAXIMUM_US = 2500,
    SERVO_HOME_US = 1500,
    SERVO_RETRACT_US = 2500,
    ROTARY_FORWARD_US = 2000,
    ROTARY_FINE_FORWARD_US = 1800,
    ROTARY_FINE_BREAKAWAY_US = 1850,
    ROTARY_SLOT_COUNT = 15,
    ROTARY_TOLERANCE_TENTHS = 10,
    ROTARY_SLOT_RECOGNITION_TENTHS = 30,
    ROTARY_CORRECTION_MS = 25,
    ROTARY_CORRECTION_ATTEMPTS = 80,
    ROTARY_TIMEOUT_MS = 8000,
    PCA9685_MODE1 = 0x00,
    PCA9685_MODE2 = 0x01,
    PCA9685_LED0_ON_L = 0x06,
    PCA9685_ALL_LED_OFF_H = 0xfd,
    PCA9685_PRESCALE = 0xfe,
};

static float clockwise_distance(float target, float current)
{
    float distance = target - current;
    if (distance < 0.0f) distance += 360.0f;
    return distance;
}

static const char *TAG = "servo_pca9685";
static bool s_initialized;
static SemaphoreHandle_t s_motion_mutex;
static float s_motion_start;
static float s_motion_target;
static float s_motion_final;
static float s_motion_error;
static const char *s_motion_reason = "not_run";
static float s_startup_zero;
static bool s_startup_zero_valid;

static float normalize_degrees(float degrees)
{
    while (degrees < 0.0f) degrees += 360.0f;
    while (degrees >= 360.0f) degrees -= 360.0f;
    return degrees;
}

void board_servo_capture_startup_zero(float degrees)
{
    nvs_handle_t nvs = 0;
    float saved = 0.0f;
    size_t size = sizeof(saved);
    bool restored = nvs_open("rotary_cal", NVS_READONLY, &nvs) == ESP_OK &&
                    nvs_get_blob(nvs, "zero_deg", &saved, &size) == ESP_OK &&
                    size == sizeof(saved) && isfinite(saved) && saved >= 0.0f &&
                    saved < 360.0f;
    if (nvs != 0) nvs_close(nvs);
    s_startup_zero = restored ? saved : normalize_degrees(degrees);
    s_startup_zero_valid = true;
    ESP_LOGI(TAG, "tray zero %s at %.2f deg (%d slots, %.2f deg/slot)",
             restored ? "restored" : "captured", s_startup_zero, ROTARY_SLOT_COUNT,
             360.0f / (float)ROTARY_SLOT_COUNT);
}

esp_err_t board_servo_set_current_zero(float *degrees)
{
    if (!s_initialized || s_motion_mutex == NULL ||
        xSemaphoreTake(s_motion_mutex, 0) != pdTRUE) {
        return ESP_ERR_INVALID_STATE;
    }
    uint16_t raw = 0;
    float current = 0.0f;
    esp_err_t result = board_mt6701_read(&raw, &current);
    if (result == ESP_OK) {
        current = normalize_degrees(current);
        nvs_handle_t nvs = 0;
        result = nvs_open("rotary_cal", NVS_READWRITE, &nvs);
        if (result == ESP_OK) result = nvs_set_blob(nvs, "zero_deg", &current, sizeof(current));
        if (result == ESP_OK) result = nvs_commit(nvs);
        if (nvs != 0) nvs_close(nvs);
        if (result == ESP_OK) {
            s_startup_zero = current;
            s_startup_zero_valid = true;
            if (degrees != NULL) *degrees = current;
            ESP_LOGI(TAG, "caregiver set tray zero at %.2f deg raw=%u", current, raw);
        }
    }
    xSemaphoreGive(s_motion_mutex);
    return result;
}

void board_servo_last_motion(float *start, float *target, float *final,
                             float *error, const char **reason)
{
    if (start != NULL) *start = s_motion_start;
    if (target != NULL) *target = s_motion_target;
    if (final != NULL) *final = s_motion_final;
    if (error != NULL) *error = s_motion_error;
    if (reason != NULL) *reason = s_motion_reason;
}

static void i2c_delay(void) { esp_rom_delay_us(5); }
static void sda(bool high) { gpio_set_level(BOARD_PCA9685_SDA_GPIO, high); }
static void scl(bool high) { gpio_set_level(BOARD_PCA9685_SCL_GPIO, high); }

static void i2c_start(void)
{
    sda(true); scl(true); i2c_delay();
    sda(false); i2c_delay(); scl(false);
}

static void i2c_stop(void)
{
    sda(false); i2c_delay(); scl(true); i2c_delay(); sda(true); i2c_delay();
}

static bool i2c_write_byte(uint8_t value)
{
    for (int bit = 7; bit >= 0; --bit) {
        sda((value & (1U << bit)) != 0);
        i2c_delay(); scl(true); i2c_delay(); scl(false);
    }
    sda(true);
    i2c_delay(); scl(true); i2c_delay();
    bool acknowledged = gpio_get_level(BOARD_PCA9685_SDA_GPIO) == 0;
    scl(false);
    return acknowledged;
}

static esp_err_t write_registers(uint8_t reg, const uint8_t *data, size_t length)
{
    i2c_start();
    bool ok = i2c_write_byte((uint8_t)(BOARD_PCA9685_ADDRESS << 1)) &&
              i2c_write_byte(reg);
    for (size_t i = 0; ok && i < length; ++i) {
        ok = i2c_write_byte(data[i]);
    }
    i2c_stop();
    return ok ? ESP_OK : ESP_ERR_NOT_FOUND;
}

static esp_err_t write_register(uint8_t reg, uint8_t value)
{
    return write_registers(reg, &value, 1);
}

static esp_err_t set_pulse(uint8_t channel, uint16_t pulse_us)
{
    if (channel >= 16) return ESP_ERR_INVALID_ARG;
    uint16_t count = board_pca9685_pulse_count(pulse_us);
    const uint8_t pwm[] = {0, 0, (uint8_t)count, (uint8_t)(count >> 8)};
    return write_registers((uint8_t)(PCA9685_LED0_ON_L + channel * 4),
                           pwm, sizeof(pwm));
}

static esp_err_t disable_channel(uint8_t channel)
{
    if (channel >= 16) return ESP_ERR_INVALID_ARG;
    const uint8_t off[] = {0, 0, 0, 0x10};
    return write_registers((uint8_t)(PCA9685_LED0_ON_L + channel * 4),
                           off, sizeof(off));
}
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

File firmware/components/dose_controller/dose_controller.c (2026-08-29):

#include "dose_controller/dose_controller.h"

#include <string.h>

static bool controller_valid(const dose_controller_t *controller)
{
    return controller != NULL && controller->load != NULL && controller->store != NULL &&
           controller->servo_cycle != NULL;
}

static bool set_state(dose_record_t *record,
                      pill_dose_event_t event,
                      int64_t updated_utc)
{
    pill_dose_state_t next;
    if (!pill_dose_transition(record->state, event, &next)) {
        return false;
    }
    record->state = next;
    record->updated_utc = updated_utc;
    return true;
}

dose_controller_result_t dose_controller_process_due(dose_controller_t *controller,
                                                      const char *occurrence_id,
                                                      int64_t intended_utc,
                                                      int64_t now_utc,
                                                      bool clock_valid)
{
    if (!controller_valid(controller) || occurrence_id == NULL || occurrence_id[0] == '\0' ||
        strlen(occurrence_id) >= PILL_OCCURRENCE_ID_MAX) {
        return DOSE_CONTROLLER_INVALID_ARGUMENT;
    }

    dose_record_t record = {0};
    bool found = false;
    if (!controller->load(controller->context, occurrence_id, &record, &found)) {
        return DOSE_CONTROLLER_STORAGE_ERROR;
    }
    if (found) {
        return DOSE_CONTROLLER_ALREADY_RECORDED;
    }

    pill_due_decision_t decision =
        pill_due_decide(clock_valid, now_utc, intended_utc, false);
    if (decision == PILL_DUE_TIME_INVALID) {
        return DOSE_CONTROLLER_TIME_INVALID;
    }
    if (decision == PILL_DUE_PENDING) {
        return DOSE_CONTROLLER_NOT_DUE;
    }

    strcpy(record.occurrence_id, occurrence_id);
    record.intended_utc = intended_utc;
    record.updated_utc = now_utc;
    record.state = PILL_DOSE_PENDING;

    if (decision == PILL_DUE_MISSED) {
        if (!set_state(&record, PILL_DOSE_MARK_MISSED, now_utc) ||
            !controller->store(controller->context, &record)) {
            return DOSE_CONTROLLER_STORAGE_ERROR;
        }
        return DOSE_CONTROLLER_MISSED;
    }

    if (!set_state(&record, PILL_DOSE_REQUEST_DISPENSE, now_utc) ||
        !controller->store(controller->context, &record)) {
        return DOSE_CONTROLLER_STORAGE_ERROR;
    }

    pill_dose_event_t servo_event = controller->servo_cycle(controller->context)
                                              ? PILL_DOSE_SERVO_SUCCEEDED
                                              : PILL_DOSE_SERVO_FAILED;
    if (!set_state(&record, servo_event, now_utc) ||
        !controller->store(controller->context, &record)) {
        return DOSE_CONTROLLER_STORAGE_ERROR;
    }

    return record.state == PILL_DOSE_DISPENSED ? DOSE_CONTROLLER_DISPENSED
                                                : DOSE_CONTROLLER_FAULT;
}

dose_controller_result_t dose_controller_recover(dose_controller_t *controller,
                                                  const char *occurrence_id)
{
    if (!controller_valid(controller) || occurrence_id == NULL || occurrence_id[0] == '\0') {
        return DOSE_CONTROLLER_INVALID_ARGUMENT;
    }

    dose_record_t record = {0};
    bool found = false;
    if (!controller->load(controller->context, occurrence_id, &record, &found)) {
        return DOSE_CONTROLLER_STORAGE_ERROR;
    }
    if (!found) {
        return DOSE_CONTROLLER_NOT_DUE;
    }
    if (record.state != PILL_DOSE_DISPENSING) {
        return DOSE_CONTROLLER_ALREADY_RECORDED;
    }
    if (!set_state(&record, PILL_DOSE_RECOVER, record.updated_utc) ||
        !controller->store(controller->context, &record)) {
        return DOSE_CONTROLLER_STORAGE_ERROR;
    }
    return DOSE_CONTROLLER_FAULT;
}

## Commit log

2026-08-29 Publish Mendo prototype release candidate
    [01_base_Mendo_EQ_Studio.stl, 02_fixed_deck.stl, 03_rotor_15_cells.stl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]
2026-08-29 Add prototype gallery and STL renders
2026-08-29 Replace broken SVG previews with OpenSCAD renders
    [render_part.scad]
2026-09-11 Refresh Mendo prototype photography
